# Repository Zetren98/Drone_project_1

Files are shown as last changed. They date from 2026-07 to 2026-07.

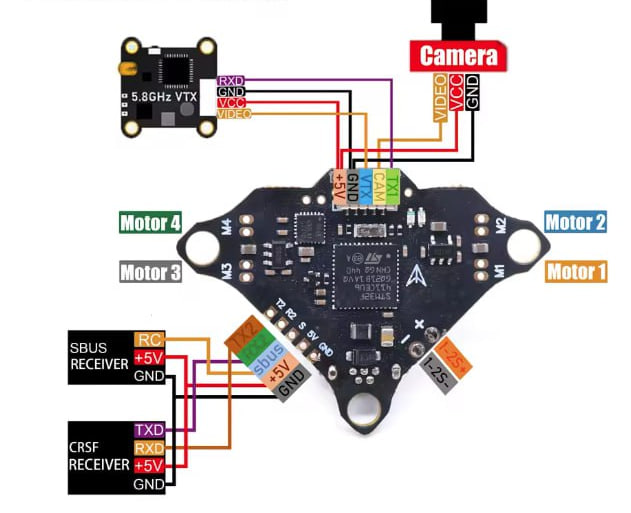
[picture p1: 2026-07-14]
Docs/Datasheets/F4DC F4 FC diagram.jpg

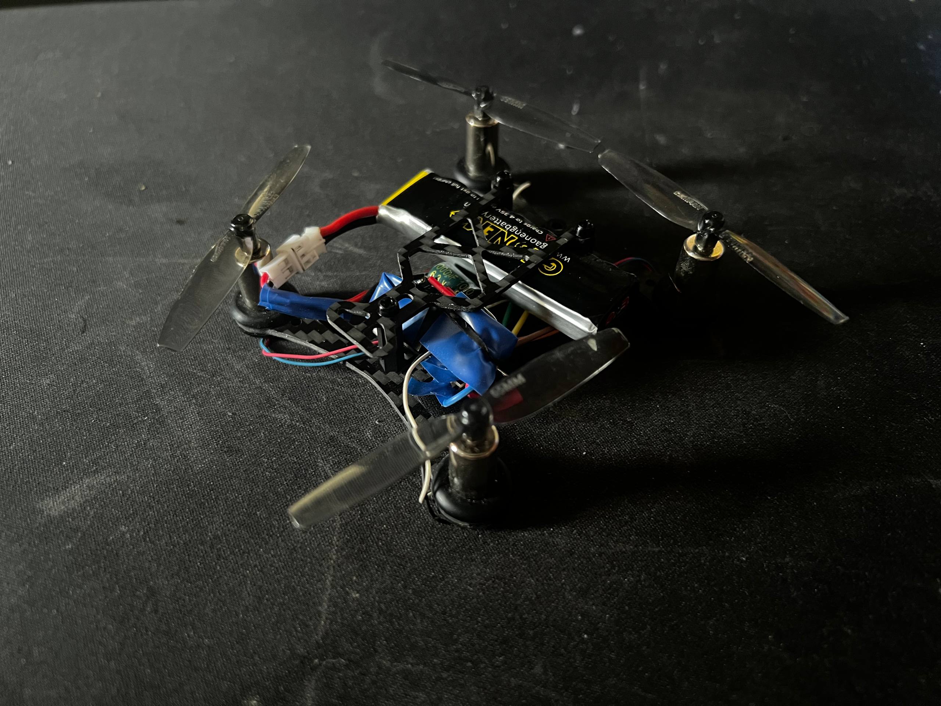
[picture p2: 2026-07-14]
Docs/Datasheets/photo_2026-07-09_17-28-56.jpg

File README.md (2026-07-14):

# Custom Drone — ESP-NOW Radio Control System

A fully custom drone build with a DIY radio control system. The drone is based on the **F4DC F411** flight controller and communicates via two **ESP8266 (ESP-01)** modules using the **ESP-NOW** protocol over Wi-Fi. Control input comes from a standard **DualShock 4** gamepad connected to a PC desktop application.

> **Languages:** C# · C

---

## How It Works

The system is split into three logical layers:

```
[DualShock 4] ──► [PC Client] ──USB──► [TX ESP-01] ──ESP-NOW──► [RX ESP-01] ──CRSF──► [Flight Controller]
```

| Layer | Role |
|---|---|
| **PC Client** | Reads stick axes from the DualShock 4 via DirectInput, converts them to RC channel values (1000–2000 µs), packs them into a binary frame and sends it over a virtual COM port to the transmitter |
| **TX (ESP-01)** | Receives packets from the PC via CP2102 USB-UART adapter, repackages them and broadcasts over ESP-NOW |
| **RX (ESP-01)** | Catches ESP-NOW packets, converts the channel data to the standard **CRSF** protocol and forwards it to the flight controller over UART |

---

## Hardware

> Exact components may be substituted with compatible alternatives.

| Component | Qty |
|---|---|
| ESP8266 Wi-Fi module (ESP-01) | 2 |
| F4DC F411 Flight Controller | 1 |
| 8520 coreless motor (2× CW + 2× CCW) | 4 |
| 65 mm 2-blade propeller, 1 mm shaft (2× CW + 2× CCW) | 4 |
| 3.8 V 660 mAh 90C Li-Po 1S | 1 |
| USB-UART converter (CP2102) | 1 |
| LD1117V33 3.3 V 950 mA linear regulator | 2 |
| 100 µF 6.3 V electrolytic capacitor | 2 |
| 1 kΩ resistor | 6 |
| Compatible frame | 1 |

Wiring diagrams and schematics are in [`/Docs`](./Docs).

---

## Repository Structure

```
Drone_project_1/
├── Docs/            # Wiring diagrams and schematics
├── Firmware/        # Betaflight backup + ESP-01 sketches (TX and RX)
├── PC_client/       # C# WPF desktop application (DroneController)
└── .gitignore
```

---

## Getting Started

### 1. Flash the ESP modules

- Flash `MAC_RX` sketch onto the **receiver** ESP-01 and note its MAC address printed over serial.
- Insert that MAC into the **transmitter** sketch, then flash the final firmware onto both ESP-01 boards.

### 2. Build the hardware

Assemble the drone and the transmitter unit following the schematics in [`/Docs`](./Docs).

### 3. Flash the flight controller

Connect the FC to Betaflight Configurator and restore the configuration backup from [`/Firmware`](./Firmware).

### 4. Build and run the PC client

Open [`/PC_client`](./PC_client) in Visual Studio 2022, target **.NET 8**, build and run.

Requirements: .NET 10 SDK, NuGet packages `SharpDX.DirectInput` and `System.IO.Ports` (restored automatically).

### 5. Connect and fly

1. Plug the DualShock 4 into the PC via USB.
2. Click **"Find and connect gamepad"** in the app — the status should turn green.
3. Select the COM port of the CP2102 transmitter and click **"Connect"**.
4. Channel bars should respond to stick input in real time.

---

## Control Mapping

| Channel | Input |
|---|---|
| Throttle | Left stick — vertical |
| Pitch | Right stick — vertical |
| Yaw | Right stick — horizontal |
| Roll | L2 (roll left) / R2 (roll right) |
| ARM | **L1** — toggle (arms only when throttle is at minimum) |
| ALTHOLD | **R1** — toggle (altitude hold via onboard barometer) |

---

## ⚠️ Safety

**Always remove propellers before any bench testing or configuration.**

Unlike a traditional RC transmitter, the throttle stick on a DualShock 4 is spring-loaded and returns to center (1500 µs ≈ 50% throttle) when released. The application will block arming if the throttle is not at the minimum position, but once armed, releasing the stick will immediately spin up the motors. Stay aware of this at all times.
=======

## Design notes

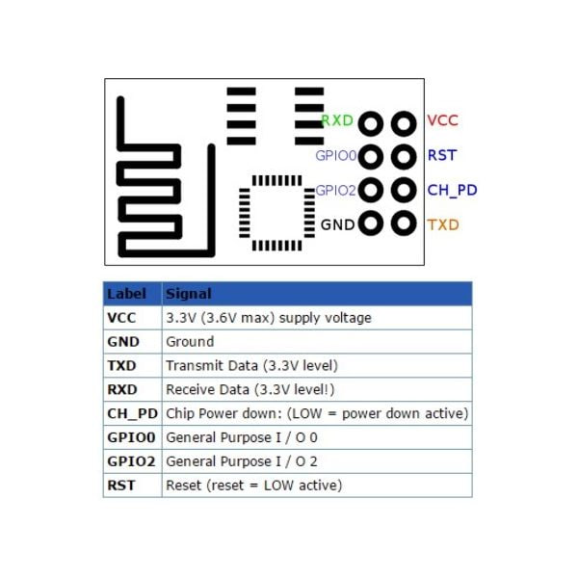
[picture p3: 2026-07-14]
Docs/Datasheets/ESP8266 diagram.jpg

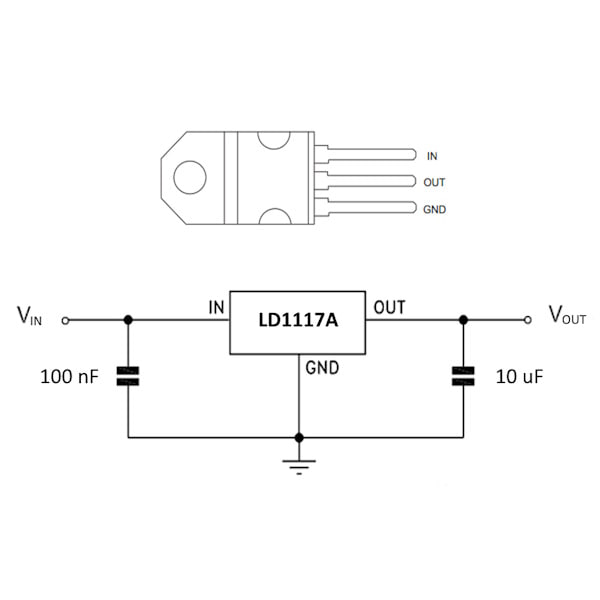
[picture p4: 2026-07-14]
Docs/Datasheets/Linear regulator diagram.jpg

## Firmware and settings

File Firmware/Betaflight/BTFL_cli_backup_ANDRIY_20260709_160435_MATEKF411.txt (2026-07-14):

defaults nosave


# version
# Betaflight / STM32F411 (S411) 4.2.0 Jun 14 2020 / 03:04:43 (8f2d21460) MSP API: 1.43

# config: YES

# start the command batch
batch start

# reset configuration to default settings
defaults nosave

board_name MATEKF411
manufacturer_id MTKS
mcu_id 003b00233134510333343336
signature 

# name: Andriy

# resources
resource BEEPER 1 B02
resource MOTOR 1 B04
resource MOTOR 2 B05
resource MOTOR 3 B06
resource MOTOR 4 B07
resource MOTOR 5 B03
resource MOTOR 6 B10
resource PPM 1 A03
resource LED_STRIP 1 A08
resource SERIAL_TX 1 A09
resource SERIAL_TX 2 A02
resource SERIAL_RX 1 A10
resource SERIAL_RX 2 A03
resource I2C_SCL 1 B08
resource I2C_SDA 1 B09
resource LED 1 C13
resource LED 2 C14
resource SPI_SCK 1 A05
resource SPI_SCK 2 B13
resource SPI_MISO 1 A06
resource SPI_MISO 2 B14
resource SPI_MOSI 1 A07
resource SPI_MOSI 2 B15
resource ADC_BATT 1 B00
resource ADC_CURR 1 B01
resource OSD_CS 1 B12
resource GYRO_EXTI 1 A01
resource GYRO_CS 1 A04
resource USB_DETECT 1 C15

# timer
timer A03 AF3
# pin A03: TIM9 CH2 (AF3)
timer B04 AF2
# pin B04: TIM3 CH1 (AF2)
timer B05 AF2
# pin B05: TIM3 CH2 (AF2)
timer B06 AF2
# pin B06: TIM4 CH1 (AF2)
timer B07 AF2
# pin B07: TIM4 CH2 (AF2)
timer B03 AF1
# pin B03: TIM2 CH2 (AF1)
timer B10 AF1
# pin B10: TIM2 CH3 (AF1)
timer A00 AF2
# pin A00: TIM5 CH1 (AF2)
timer A02 AF2
# pin A02: TIM5 CH3 (AF2)
timer A08 AF1
# pin A08: TIM1 CH1 (AF1)

# dma
dma ADC 1 1
# ADC 1: DMA2 Stream 4 Channel 0
dma pin B04 0
# pin B04: DMA1 Stream 4 Channel 5
dma pin B05 0
# pin B05: DMA1 Stream 5 Channel 5
dma pin B06 0
# pin B06: DMA1 Stream 0 Channel 2
dma pin B07 0
# pin B07: DMA1 Stream 3 Channel 2
dma pin B03 0
# pin B03: DMA1 Stream 6 Channel 3
dma pin B10 0
# pin B10: DMA1 Stream 1 Channel 3
dma pin A00 0
# pin A00: DMA1 Stream 2 Channel 6
dma pin A02 0
# pin A02: DMA1 Stream 0 Channel 6
dma pin A08 0
# pin A08: DMA2 Stream 6 Channel 0

# feature
feature -RX_PARALLEL_PWM
feature RX_SERIAL
feature MOTOR_STOP
feature TELEMETRY
feature LED_STRIP
feature OSD

# serial
serial 0 2048 115200 57600 0 115200
serial 1 64 115200 57600 0 115200

# led
led 0 4,4::CB:4
led 1 5,4::CB:11

# aux
aux 0 0 0 1700 2100 0 0
aux 1 1 1 1700 2100 0 0

# vtxtable
vtxtable bands 5
vtxtable channels 8
vtxtable band 1 BOSCAM_A A FACTORY 5865 5845 5825 5805 5785 5765 5745 5725
vtxtable band 2 BOSCAM_B B FACTORY 5733 5752 5771 5790 5809 5828 5847 5866
vtxtable band 3 BOSCAM_E E FACTORY 5705 5685 5665 5645 5885 5905 5925 5945
vtxtable band 4 FATSHARK F FACTORY 5740 5760 5780 5800 5820 5840 5860 5880
vtxtable band 5 RACEBAND R FACTORY 5658 5695 5732 5769 5806 5843 5880 5917
vtxtable powerlevels 3
vtxtable powervalues 0 1 2
vtxtable powerlabels 25 100 200

# master
set acc_calibration = 39,5,-12,1
set align_mag = CW180
set mag_align_yaw = 1800
set mag_bustype = I2C
set mag_i2c_device = 1
set baro_bustype = I2C
set baro_i2c_device = 1
set max_check = 2000
set serialrx_provider = CRSF
set min_throttle = 1070
set dshot_burst = AUTO
set dshot_bitbang = OFF
set use_unsynced_pwm = OFF
set motor_pwm_rate = 10000
set bat_capacity = 650
set vbat_max_cell_voltage = 440
set current_meter = NONE
set battery_meter = ADC
set ibata_scale = 16000
set beeper_inversion = ON
set beeper_od = OFF
set yaw_motors_reversed = ON
set 3d_deadband_throttle = 30
set deadband = 5
set yaw_deadband = 5
set osd_tim2 = 513
set osd_vbat_pos = 2433
set osd_rssi_pos = 2401
set osd_tim_1_pos = 54
set osd_tim_2_pos = 2454
set osd_flymode_pos = 2423
set osd_throttle_pos = 225
set osd_vtx_channel_pos = 377
set osd_crosshairs_pos = 2253
set osd_current_pos = 385
set osd_mah_drawn_pos = 353
set osd_craft_name_pos = 2441
set osd_gps_speed_pos = 218
set osd_gps_lon_pos = 82
set osd_gps_lat_pos = 65
set osd_gps_sats_pos = 51
set osd_home_dir_pos = 302
set osd_home_dist_pos = 303
set osd_compass_bar_pos = 42
set osd_altitude_pos = 247
set osd_pid_roll_pos = 423
set osd_pid_pitch_pos = 455
set osd_pid_yaw_pos = 487
set osd_debug_pos = 1
set osd_power_pos = 321
set osd_pidrate_profile_pos = 345
set osd_warnings_pos = 2282
set osd_avg_cell_voltage_pos = 76
set osd_pit_ang_pos = 33
set osd_rol_ang_pos = 65
set osd_battery_usage_pos = 392
set osd_disarmed_pos = 2379
set osd_nheading_pos = 311
set osd_nvario_pos = 279
set osd_esc_tmp_pos = 82
set osd_esc_rpm_pos = 83
set osd_core_temp_pos = 268
set osd_stat_tim_1 = ON
set osd_stat_endbatt = ON
set system_hse_mhz = 8
set max7456_spi_bus = 2
set gyro_1_bustype = SPI
set gyro_1_spibus = 1
set gyro_1_sensor_align = CW180
set gyro_1_align_yaw = 1800
set name = Andriy

profile 0

profile 1

profile 2

# restore original profile selection
profile 0

rateprofile 0

rateprofile 1

rateprofile 2

rateprofile 3

rateprofile 4

rateprofile 5

# restore original rateprofile selection
rateprofile 0

# save configuration

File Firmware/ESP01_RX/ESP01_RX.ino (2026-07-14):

#include <ESP8266WiFi.h>
extern "C" {
  #include <espnow.h>
  #include <user_interface.h>
}
#include <string.h>
#define WIFI_CHANNEL             1
#define CRSF_BAUD                420000
#define CRSF_UPDATE_INTERVAL_MS  14
#define FAILSAFE_TIMEOUT_MS      500
typedef struct __attribute__((packed)) {
  uint8_t  magic;
  uint16_t ch[6];
} espnow_packet_t;

volatile espnow_packet_t lastPacket;
volatile unsigned long   lastRxMillis = 0;
volatile bool            havePacket = false;

#define CRSF_ADDR_FC           0xC8
#define CRSF_TYPE_RC_CHANNELS  0x16
#define CRSF_RC_FRAME_LEN      24

typedef struct __attribute__((packed)) {
  unsigned ch0:11;  unsigned ch1:11;  unsigned ch2:11;  unsigned ch3:11;
  unsigned ch4:11;  unsigned ch5:11;  unsigned ch6:11;  unsigned ch7:11;
  unsigned ch8:11;  unsigned ch9:11;  unsigned ch10:11; unsigned ch11:11;
  unsigned ch12:11; unsigned ch13:11; unsigned ch14:11; unsigned ch15:11;
} crsfChannels_t;

uint8_t crc8_dvb_s2(const uint8_t *buf, uint8_t len) {
  uint8_t crc = 0;
  for (uint8_t i = 0; i < len; i++) {
    crc ^= buf[i];
    for (uint8_t b = 0; b < 8; b++) {
      crc = (crc & 0x80) ? (uint8_t)((crc << 1) ^ 0xD5) : (uint8_t)(crc << 1);
    }
  }
  return crc;
}

uint16_t usToCrsf(uint16_t us) {
  int32_t v = ((int32_t)us - 1500) * 8 / 5 + 992;
  if (v < 172)  v = 172;
  if (v > 1811) v = 1811;
  return (uint16_t)v;
}

void sendCrsfFrame(uint16_t *crsfVals) {
  uint8_t frame[26];
  frame[0] = CRSF_ADDR_FC;
  frame[1] = CRSF_RC_FRAME_LEN;
  frame[2] = CRSF_TYPE_RC_CHANNELS;

  crsfChannels_t packed;
  packed.ch0  = crsfVals[0];  packed.ch1  = crsfVals[1];  packed.ch2  = crsfVals[2];  packed.ch3  = crsfVals[3];
  packed.ch4  = crsfVals[4];  packed.ch5  = crsfVals[5];  packed.ch6  = crsfVals[6];  packed.ch7  = crsfVals[7];
  packed.ch8  = crsfVals[8];  packed.ch9  = crsfVals[9];  packed.ch10 = crsfVals[10]; packed.ch11 = crsfVals[11];
  packed.ch12 = crsfVals[12]; packed.ch13 = crsfVals[13]; packed.ch14 = crsfVals[14]; packed.ch15 = crsfVals[15];

  memcpy(&frame[3], &packed, 22);
  frame[25] = crc8_dvb_s2(&frame[2], 23);

  Serial.write(frame, 26);
}

void onReceive(uint8_t *mac, uint8_t *data, uint8_t len) {
  if (len == sizeof(espnow_packet_t)) {
    espnow_packet_t *p = (espnow_packet_t *)data;
    if (p->magic == 0xC5) {
      memcpy((void *)&lastPacket, p, sizeof(espnow_packet_t));
      lastRxMillis = millis();
      havePacket = true;
    }
  }
}

unsigned long lastSend = 0;

void setup() {
  Serial.begin(CRSF_BAUD);

  WiFi.mode(WIFI_STA);
  WiFi.disconnect();
  wifi_set_channel(WIFI_CHANNEL);

  esp_now_init();
  esp_now_set_self_role(ESP_NOW_ROLE_SLAVE);
  esp_now_register_recv_cb(onReceive);
}

void loop() {
  unsigned long now = millis();
  if (now - lastSend >= CRSF_UPDATE_INTERVAL_MS) {
    lastSend = now;

    if (havePacket && (now - lastRxMillis) < FAILSAFE_TIMEOUT_MS) {
      uint16_t us[6];
      memcpy(us, (void *)lastPacket.ch, sizeof(us));

      uint16_t crsfVals[16];
      crsfVals[0] = usToCrsf(us[1]);
      crsfVals[1] = usToCrsf(us[2]);
      crsfVals[2] = usToCrsf(us[0]);
      crsfVals[3] = usToCrsf(us[3]);
      crsfVals[4] = usToCrsf(us[4]);
      crsfVals[5] = usToCrsf(us[5]);
      for (int i = 6; i < 16; i++) crsfVals[i] = 992;
      sendCrsfFrame(crsfVals);
    }
  }
}

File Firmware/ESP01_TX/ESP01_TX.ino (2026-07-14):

#include <ESP8266WiFi.h>
extern "C" {
  #include <espnow.h>
  #include <user_interface.h>
}
#include <string.h>

#define WIFI_CHANNEL 1
#define UART_BAUD    115200
uint8_t receiverMac[6] = {0x00, 0x00, 0x00, 0x00, 0x00, 0x00}; //Enter the receiver's MAC address
typedef struct __attribute__((packed)) {
  uint8_t  magic;
  uint16_t ch[6];
} espnow_packet_t;

enum { WAIT_SYNC1, WAIT_SYNC2, READ_PAYLOAD };
uint8_t parseState = WAIT_SYNC1;
uint8_t rxBuf[13];
uint8_t rxIdx = 0;

void sendToReceiver(uint16_t *ch) {
  espnow_packet_t pkt;
  pkt.magic = 0xC5;
  memcpy(pkt.ch, ch, sizeof(pkt.ch));
  esp_now_send(receiverMac, (uint8_t*)&pkt, sizeof(pkt));
}

void handleByte(uint8_t b) {
  switch (parseState) {
    case WAIT_SYNC1:
      if (b == 0xAA) parseState = WAIT_SYNC2;
      break;

    case WAIT_SYNC2:
      if (b == 0x55) { parseState = READ_PAYLOAD; rxIdx = 0; }
      else parseState = WAIT_SYNC1;
      break;

    case READ_PAYLOAD:
      rxBuf[rxIdx++] = b;
      if (rxIdx >= 13) {
        parseState = WAIT_SYNC1;

        uint8_t chk = 0;
        for (int i = 0; i < 12; i++) chk ^= rxBuf[i];

        if (chk == rxBuf[12]) {
          uint16_t ch[6];
          for (int i = 0; i < 6; i++) {
            ch[i] = rxBuf[i * 2] | (rxBuf[i * 2 + 1] << 8);
          }
          sendToReceiver(ch);
        }
      }
      break;
  }
}

void setup() {
  Serial.begin(UART_BAUD);

  WiFi.mode(WIFI_STA);
  WiFi.disconnect();
  wifi_set_channel(WIFI_CHANNEL);

  esp_now_init();
  esp_now_set_self_role(ESP_NOW_ROLE_CONTROLLER);
  esp_now_add_peer(receiverMac, ESP_NOW_ROLE_SLAVE, WIFI_CHANNEL, NULL, 0);
}

void loop() {
  while (Serial.available()) {
    handleByte((uint8_t)Serial.read());
  }
}
